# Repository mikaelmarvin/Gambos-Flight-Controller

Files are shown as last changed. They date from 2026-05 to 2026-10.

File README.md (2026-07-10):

# Gambos flight controller

Custom **STM32F446** flight-controller PCB and firmware — schematic through layout, manufacture, assembly, bring-up, application and driver development.

## At a glance

| | |
| ---| ---|
| **MCU** | STM32F446RET6 (Cortex-M4 + FPU) |
| **Sensors** | Accelerometer, gyroscope, magnetometer, barometer, temperature |
| **Storage** | External flash + microSD |
| **Actuation** | 5× hobby servo PWM, ESC motor PWM |
| **Wireless**  | nRF24L01+ telemetry / command link |
| **Debug** | SWD + UART (SEGGER J-Link) |
| **PCB** | 4-layer, 75 × 50 mm — KiCad, manufactured **v1.0** |
| **Firmware**  | CMake, FreeRTOS — `gambos-pcb` target |
| **Status** | v1.0 built; hardware bring-up in progress; flight software in progress |
| **Schematic** | [Gambos PCB schematic (PDF)](docs/gambos-pcb.pdf) — KiCad export, v1.0 |

## Schematic (v1.0)

The full board schematic is published as a PDF:

**[Gambos PCB schematic (PDF)](docs/gambos-pcb.pdf)**

The editable design lives in the KiCad project under [`hardware/`](hardware/); the PDF is an export of that source.

## Render and Bring-up setup

<p align="center">
  <table cellspacing="0" cellpadding="12">
    <tr>
      <td align="center" valign="top">
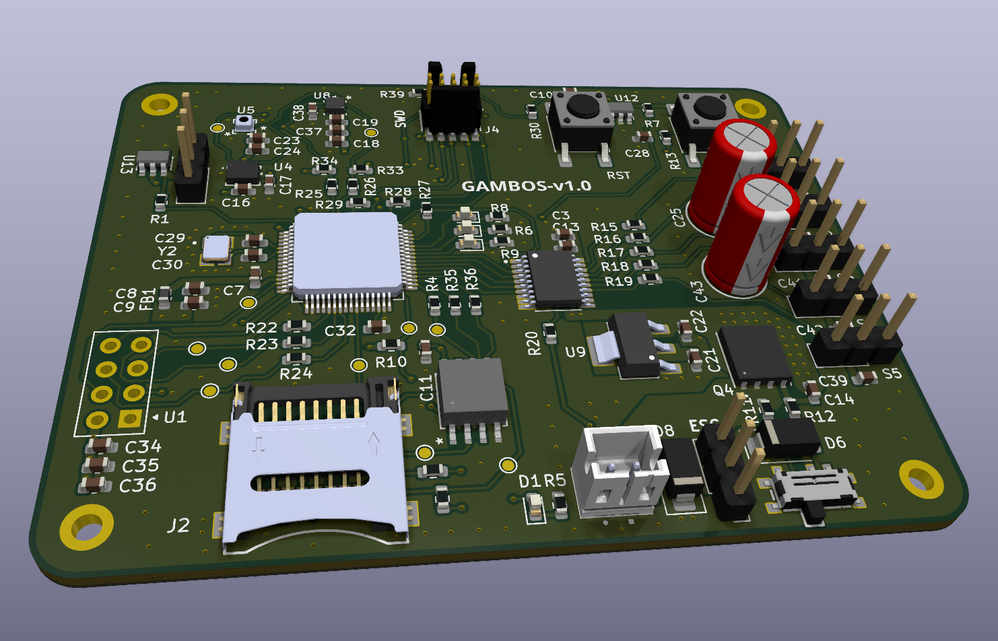
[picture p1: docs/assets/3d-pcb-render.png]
3D PCB render
        
        <br>
        <sub>3D PCB render</sub>
      </td>
      <td align="center" valign="top">
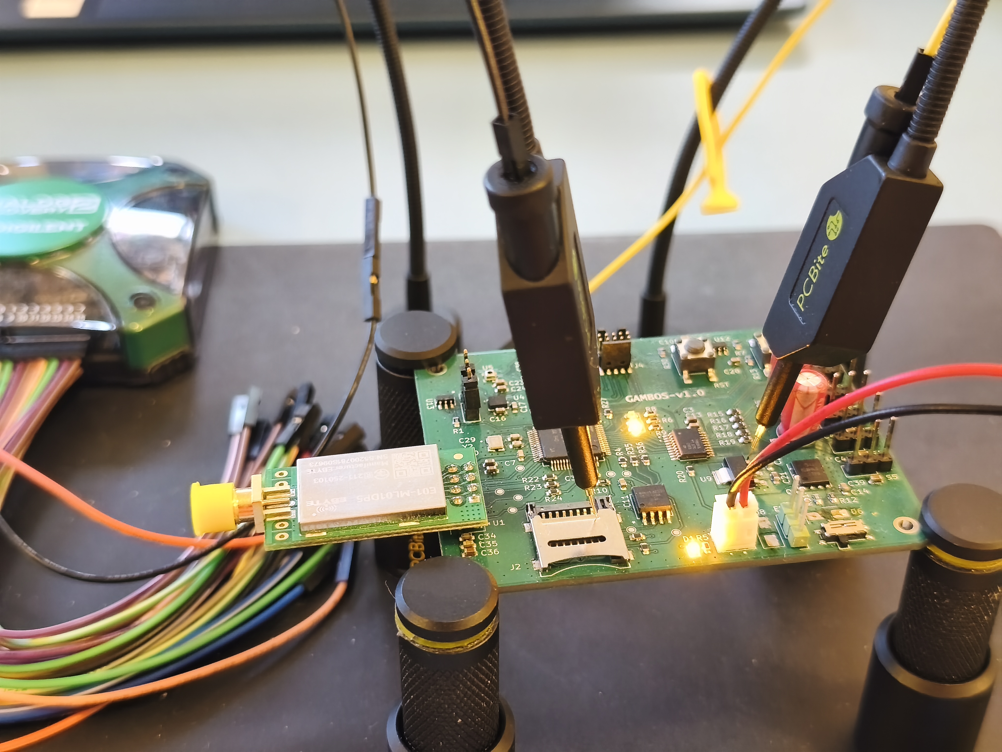
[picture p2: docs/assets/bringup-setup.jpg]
Bring-up setup on the bench
        
        <br>
        <sub>Testing the power section on the bench</sub>
      </td>
    </tr>
  </table>
</p>

Render of v1.0 layout in KiCad (left) and early bench bring-up (right), started with the power section before moving to testing other peripherals.

## Hardware block diagram

<p align="center">
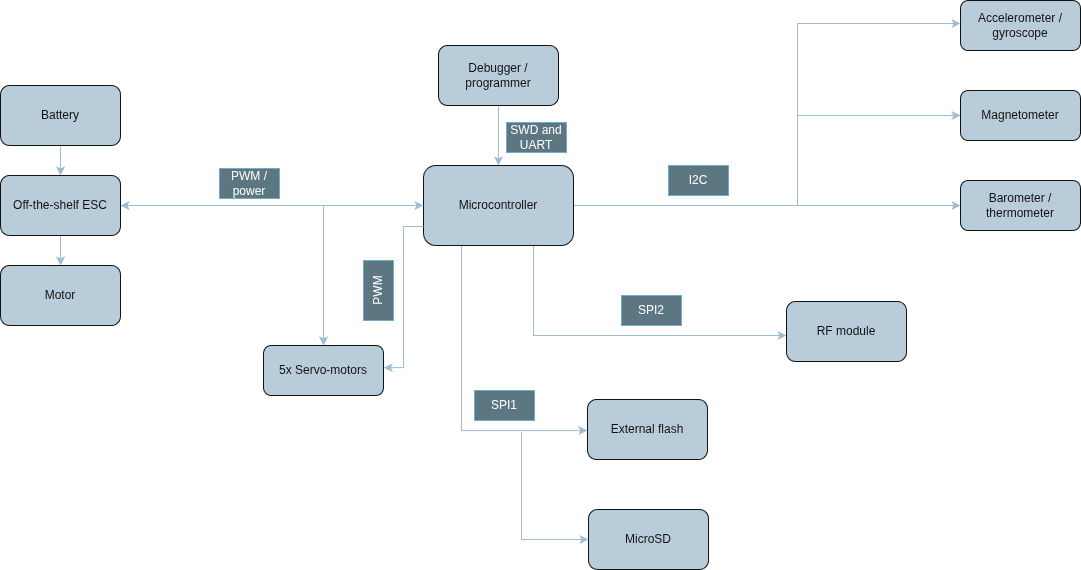
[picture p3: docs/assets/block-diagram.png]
System block diagram
  
  <br>
  <sub>Hardware block diagram</sub>
</p>

Buses, actuation, and interfaces are described in [Hardware architecture](docs/hardware/hardware-architecture.md).

## Software architecture

*(diagram pending)* — layer stack, drivers, RTOS tasks, and flight logic are described in [Software architecture](docs/software/software-architecture.md).

## Documentation

Full index: **[docs/index.md](docs/index.md)**

**Hardware** (read in order after this page):

1. [Hardware architecture](docs/hardware/hardware-architecture.md)
2. [Physical design](docs/hardware/physical-design.md)
3. [Power](docs/hardware/power.md) → [Storage](docs/hardware/storage.md) → [Sensing](docs/hardware/sensing.md) → [User interface](docs/hardware/user-interface.md)
4. [Roadmap](docs/hardware/roadmap.md) — v1.0 todos and v1.1+ hardware plans

**Software:** [docs/software/software-architecture.md](docs/software/software-architecture.md) → [software/README.md](software/README.md)

## Repository layout

| Directory | Purpose |
| --- | --- |
| `[hardware/](hardware/)` | KiCad project, libraries, manufacturing outputs |
| `[software/](software/)` | STM32 firmware (CMake, FreeRTOS) |
| `[docs/](docs/)` | Hardware and software documentation, figures |

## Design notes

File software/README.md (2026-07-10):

# Gambos firmware

STM32 firmware for the Gambos project — built with CMake, developed in a **Dev Container** (Docker) at the **repository root** (see the top-level `README.md`).

## Prerequisites

| Requirement | Notes |
| ---| ---|
| **Git** | Clone this repository. |
| **Docker** + **Docker Compose** | Used by the dev container. |
| **Cursor** or **VS Code** | With the **Dev Containers** extension (`ms-vscode-remote.remote-containers`). |
| **Host OS** | **Linux** recommended for **USB** (J-Link, serial) into the container. |

## First-time setup (after clone)

1. **Open the repo in the editor** and choose **“Reopen in Container”** (or **Dev Containers: Reopen in Container**).
2. Wait for the image to build and **post-create** to finish. The container runs `.devcontainer/setup.sh`, which runs `./software/project/scripts/build.sh`.
3. **Open a new terminal** so the shell prompt (Starship) and `PATH` are correct.

## Build, flash, probe, clean, and pristine

Run from the **repository root** via `software/project/scripts/`.

| Argument | Hardware | Debugger |
| --- | --- | --- |
| `gambos-pcb` (default) | Gambos PCB | **SEGGER J-Link** (`JLinkExe`) |

| Script | Role |
| ---| ---|
| `build.sh` | Configure + compile → `build/gambos-pcb/gambos.elf` |
| `clean.sh` | CMake `clean` |
| `pristine.sh` / `pristine.sh all` | Delete entire `build/` |
| `pristine.sh gambos-pcb` | Delete only `build/gambos-pcb/` |
| `flash.sh` | Program the MCU (build first) |
| `probe.sh` | Verify debugger connection |

```bash
./software/project/scripts/build.sh
./software/project/scripts/clean.sh
./software/project/scripts/pristine.sh          # or pristine.sh gambos-pcb | all
./software/project/scripts/flash.sh
./software/project/scripts/probe.sh             # optional before flash
```

## Editor / clangd (IntelliSense)

- `compile_commands.json` is generated under `software/project/build/gambos-pcb/` when you build. A symlink at `software/project/compile_commands.json` points at that directory.
- **clangd path mappings** in `.devcontainer/devcontainer.json` and `.vscode/settings.json` translate host paths (`/home/mikael/gambos`) and container paths (`/workspace/gambos`) so IntelliSense works whether you built on the host or in the Dev Container — no file rewriting.
- CMSIS-SVD for register view in Cortex-Debug: `software/STM32F446.svd` (referenced from `.vscode/launch.json`).
- `software/.clangd` points firmware sources at the `board` compilation database.
- If clangd is stale, run `./software/project/scripts/build.sh`, then **restart clangd** (command palette: **clangd: Restart language server**).

## Debugging

**Run and Debug (F5):** **Debug** or **Attach gambos-pcb (J-Link)** — see `.vscode/launch.json`. Symbols from `build/gambos-pcb/gambos.elf`; build (and flash if needed) first.

**Before F5**

1. In a terminal: `./software/project/scripts/build.sh` so the ELF exists and matches your code.
2. Optionally `flash.sh` / `probe.sh` if you want to verify outside the debugger.

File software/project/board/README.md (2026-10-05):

# Board support

## Gambos PCB (`gambos-pcb`)

`board/gambos-pcb/` is the **committed STM32CubeMX export** used by CMake.

| Path | Role |
|---|---|
| `board/gambos-pcb/` | CubeMX project (`.ioc`, `Core/`, HAL, FreeRTOS, generated CMake) |
| `app/gambos-pcb/` | Application code |
| `custom_drivers/` | Hardware drivers |

### CubeMX regeneration

1. Open `board/gambos-pcb/gambos-pcb.ioc` in CubeMX.
2. Generate code into the same `board/gambos-pcb/` directory (overwrite).
3. Review `git diff` — keep project hooks inside `USER CODE` blocks.
4. Build:

```bash
./software/project/scripts/build.sh
```

Put pins, clocks, timers, NVIC, and FreeRTOS parameters in the `.ioc`. Put application glue only in Cube `USER CODE` sections (for example `app_init()` in `Core/Src/main.c`).

`board/gambos-pcb/CMakeLists.txt` is **CubeIDE-only**. The firmware build uses `board/gambos-pcb/cmake/stm32cubemx/` via the top-level `CMakeLists.txt`.

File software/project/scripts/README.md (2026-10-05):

# `software/project/scripts`

Run these from the **repository root**.

## Probe & flash (Gambos PCB / J-Link)

| Command | Hardware | Probe | Flash |
|---|---|---|---|
| `./software/project/scripts/probe.sh` | Gambos PCB — **SEGGER J-Link** | `./software/project/scripts/probe.sh` | `./software/project/scripts/flash.sh` |

Build first:

```bash
./software/project/scripts/build.sh
```

Optional env:

- **`GAMBOS_FLASH_ELF`** — explicit ELF for `flash.sh`
- **`GAMBOS_JLINK_DEVICE`**, **`GAMBOS_JLINK_SPEED`** — J-Link tuning

## Other scripts

| Script | Role |
|---|---|
| `build.sh` | Configure + compile → `build/gambos-pcb/gambos.elf` |
| `clean.sh` | CMake `clean` for `gambos-pcb` |
| `pristine.sh` / `pristine.sh all` | Delete entire `build/` |
| `pristine.sh gambos-pcb` | Delete only `build/gambos-pcb/` |

USB debug probes need **`/dev/bus/usb`** (see repo `docker-compose.yml`). Install SEGGER in the image (repo `Dockerfile`) and rebuild the Dev Container.

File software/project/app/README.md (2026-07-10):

# Application

The Gambos PCB application lives in `app/gambos-pcb/`. Sources are listed in `app/gambos-pcb/CMakeLists.txt` (included from the top-level `CMakeLists.txt`).

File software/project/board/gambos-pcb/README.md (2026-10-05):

# Gambos PCB — CubeMX board tree

Committed STM32CubeMX export for the Gambos PCB. CMake builds this directory directly.

- Edit hardware config in `gambos-pcb.ioc`, then regenerate into this folder.
- Keep project-specific C hooks inside `USER CODE` blocks only.
- Application code lives in `app/gambos-pcb/`; drivers in `custom_drivers/`.

See [`../README.md`](../README.md) for the regeneration workflow.

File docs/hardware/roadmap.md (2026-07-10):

# Roadmap

Open work on **v1.0** (current board, firmware, and docs in this repository) and planned changes for **later hardware iterations**. Move items to done as they complete; add v1.1+ entries only when they target a new PCB spin, not v1.0 bring-up.

## Current iteration (v1.0)

### Hardware

- Document assembly and bench test procedure (or link from bring-up notes)

### Firmware

- Complete Gambos PCB peripheral bring-up on `gambos-pcb` preset (I2C sensors, SPI flash, SD, SPI2 RF)
- RTOS task layout, drivers, and messaging (see [Software architecture](../software/software-architecture.md))
- Sensor fusion and control loops for fixed-wing flight
- In-flight logging on external flash; post-flight copy to SD
- Telemetry protocol over nRF24L01+

### Documentation

- Software architecture page: layer diagram, tasks, drivers structure
- Hardware pages: fill placeholders (e.g. power measurements, LDO notes)
- BOM with manufacturer part numbers in repo or linked spreadsheet
- Testing of bulk capacitors on servo motors and their response -> osciloscope measuring

## Next hardware iteration (v1.1+)

Changes intended for a **future PCB revision** after v1.0 bring-up and flight tests — not general repo todos.

### Fixes from v1.0 bring-up

- S2 pin, which is dedicated to the SERVO2 motor cannot be mapped to a hardware generated PWM signal in stm32cubemx, thus making this hardware version not be able to control 5 servos, but 4 (S1, S3, S4, S5).

### Design improvements under consideration

- Copper pour and stitching can be done in a more elegant way
- Add a GNSS module with a ready made antenna, 
- BLE would be interesting
- Humidity sensor
- Ditch the MUTAG ESD component; it is a nightmare to solder -> general component selection optimized for easier soldering

---

**Next:** [Documentation index →](../index.md)

[Repository README](../../README.md) · [Documentation index](../index.md)

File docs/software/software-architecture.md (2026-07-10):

# Software architecture

Firmware for Gambos lives under [`software/`](../../software/).

| | |
| --- | --- |
| **MCU** | STM32F446 — Gambos PCB (`gambos-pcb`) |
| **Build** | CMake, FreeRTOS, STM32 HAL |
| **Status** | Build/flash workflow documented; flight-stack architecture docs not written yet |

## Getting started

**[software/README.md](../../software/README.md)** — Dev Container, build, flash, and debug scripts.

## Software architecture *(documentation in progress)*

Expand these sections on this page (or add linked pages) as the stack matures. The [repository README](../../README.md) lists the same placeholders for recruiters landing on the repo root.

## Related documentation

- [Repository README](../../README.md)
- [Hardware architecture](../hardware/hardware-architecture.md)
- [Roadmap](../hardware/roadmap.md)

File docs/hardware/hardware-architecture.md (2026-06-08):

# Hardware architecture

**Schematic:** [Gambos PCB schematic (PDF)](../gambos-pcb.pdf) (KiCad v1.0 export).

## Block diagram

System block diagram

## Digital communication

### Sensors (I2C)

All primary flight sensors (accelerometer, gyroscope, magnetometer, barometer) share one **I2C** bus. This keeps routing and pin usage simple; bandwidth is sufficient at the planned sample rates.

### Non-volatile storage (SPI1)

**External flash** and the **microSD** card share **SPI1**. Flash holds high-rate in-flight logs; the SD card is used after flight to copy data for long-term storage, so firmware can avoid bus contention during flight.

### Telemetry (SPI2)

The **nRF24L01+** uses **SPI2** on its own bus so the RF driver does not share the SPI peripheral with storage devices — simpler firmware and predictable timing.

## Actuation and power control

### Flight surfaces

Five servos are driven by **hardware PWM**. They are powered from the ESC **BEC** rail so high-current inductive loads stay off the logic supply.

### Propulsion

The brushless motor is driven by a dedicated **PWM** signal to the ESC. Battery power routes directly from the Li-Po pack to the ESC high-voltage inputs.

## Debugging and development

### SWD (Serial Wire Debug)

A dedicated header supports flashing, breakpoints, and real-time variable inspection.

### Serial console (UART)

UART on the debug header streams development logs and telemetry during bring-up.

---

**Next:** [Physical design →](physical-design.md)

[Documentation index](../index.md)

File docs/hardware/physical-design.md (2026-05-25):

# Physical design

The board uses a **4-layer stackup** for signal integrity and power distribution:

| Layer | Role |
| ---| ---|
| 1 (Top) | Signal / power |
| 2 | Ground plane |
| 3 | Ground plane |
| 4 (Bottom) | Signal / power |

Dual internal ground planes give a low-impedance return path. Outer layers use copper pours for thermal spread and to limit warping during reflow and hand soldering.

**Board size:** 75 × 50 mm

<p align="center">
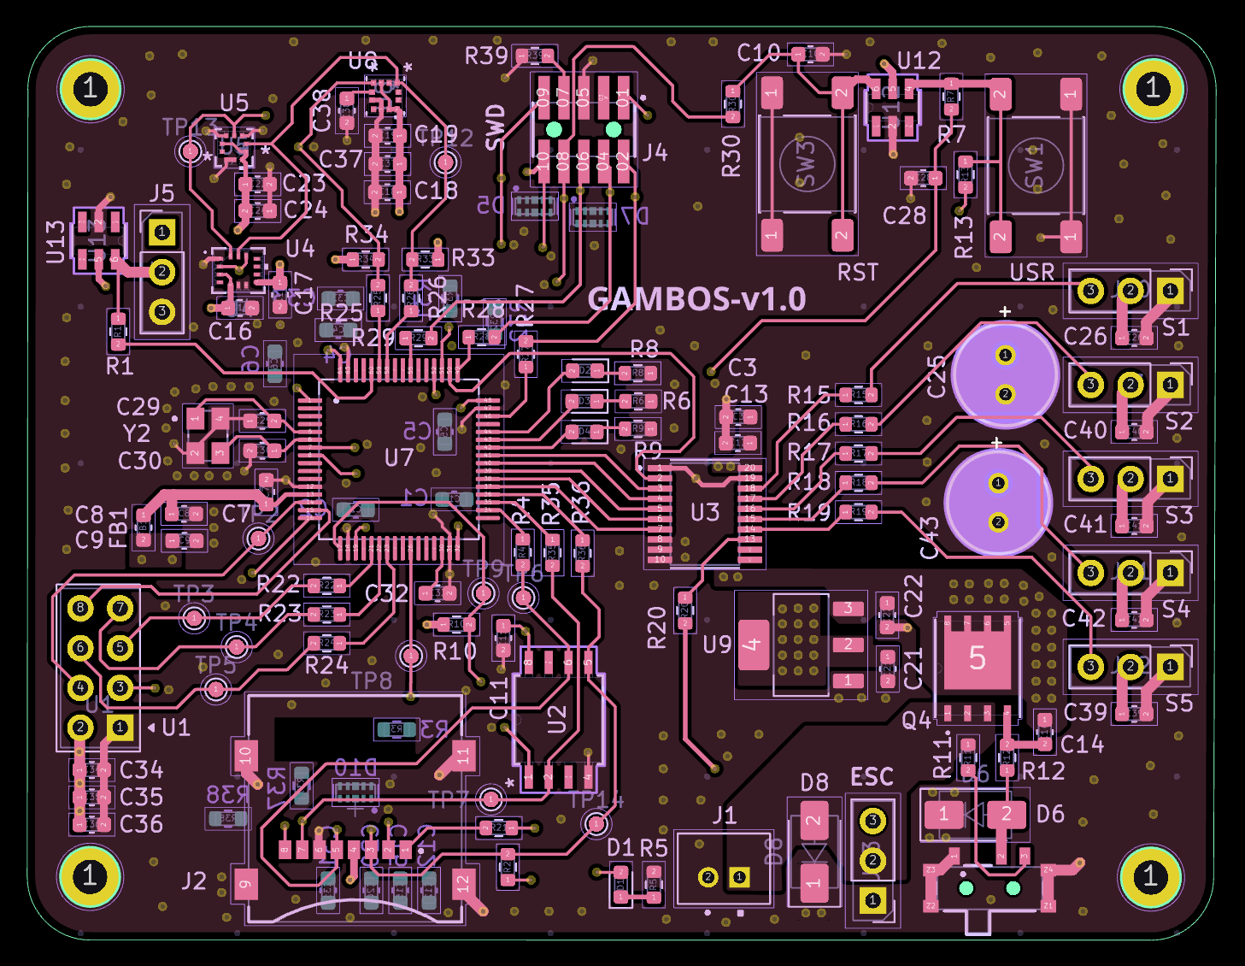
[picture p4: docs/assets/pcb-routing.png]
PCB routing
  
  <br>
  <sub>Top-layer with copper pour</sub>
</p>

---

**Next:** [Power →](power.md)

[Documentation index](../index.md)

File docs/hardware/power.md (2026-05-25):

# Power section

The power path feeds the **servo rail (5 V BEC)** and the **logic rail (3.3 V)** from the battery input. A slide switch and **high-side PMOS** enable the high-current 5 V path; an **LDO** derives 3.3 V for the MCU and sensors.

| Block | Role |
| ----- | ---- |
| Slide switch | Main input enable |
| High-side PMOS + soft-start (C14) | Switched 5 V to servos; limits inrush |
| LDO | 5 V → 3.3 V for MCU and sensors |
| Bulk / decoupling | Rail stability on 5 V and 3.3 V |
| Servo headers | High-current outputs on the BEC path |

## Schematic

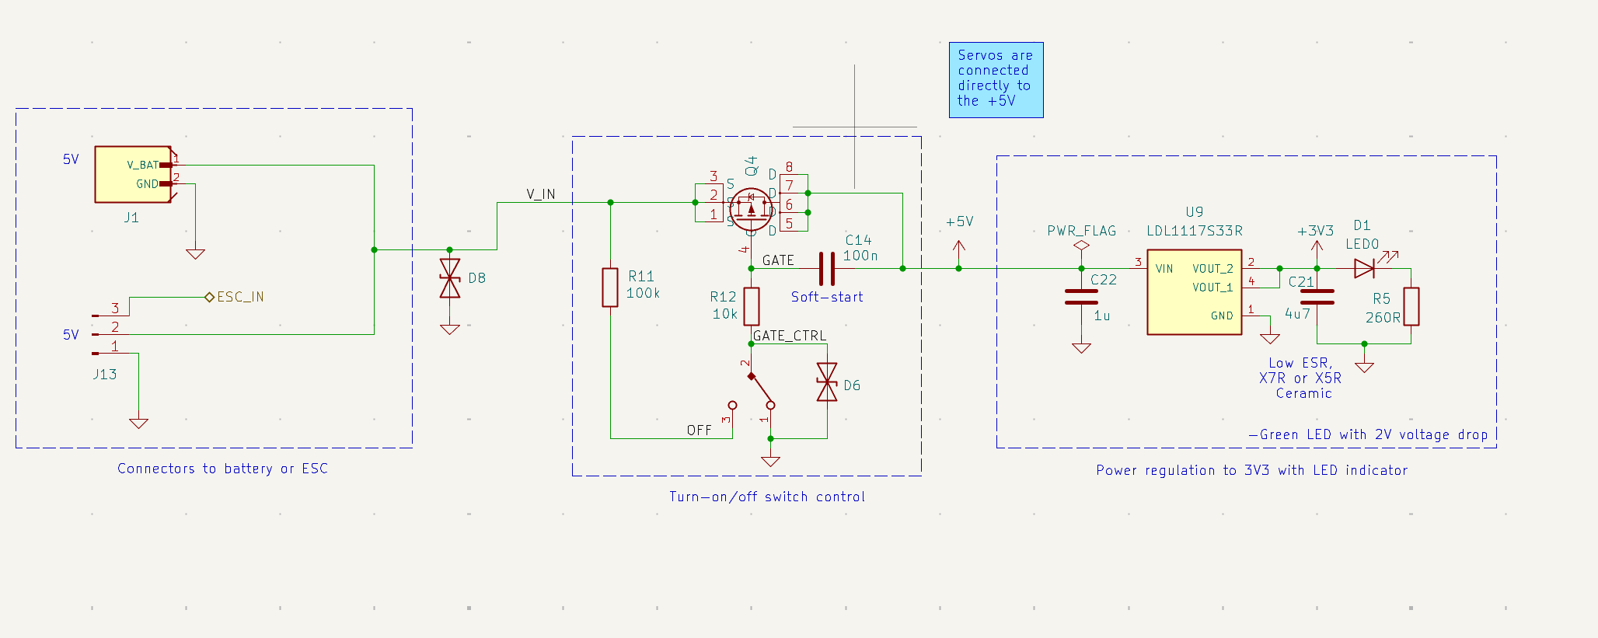
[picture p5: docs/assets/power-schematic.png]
Power schematic


## Design — high-side PMOS and soft-start

A **high-side PMOS** switches the board on and off. Five hobby servos on the **5 V** rail draw large **stall currents**, and bulk capacitance on that rail produces a high **inrush** if the FET turns on instantly.

A **100 nF soft-start capacitor (C14)** between gate and drain slows the turn-on and limits inrush. The FET is sized for roughly **750 mA** per servo stall; design headroom targets **~5 A** steady capability with inrush limited to about **10 A for 1 ms**, in line with the device datasheet. At the intended gate drive, **R<sub>DS(on)</sub>** is on the order of **10 mΩ**, so conduction loss stays acceptable even during short high-current events.

## Design — LDO (3.3 V)

*(Brief note on LDO choice, input range, and expected load — MCU + sensors on 3.3 V.)*

---

## Simulation (LTspice)

Pre-layout checks in LTspice; schematics and `.asc` files can live under `hardware/` or a linked archive when added.

| Plot | File (add under `docs/assets/`) | What it should show |
| ---- | --- | --- |
| Soft-start / inrush | `power-soft-start-sim.png` | Gate drive and 5 V rail during enable |
| PMOS switch / load | `power-pmos-load-sim.png` | Steady-state or switched load on 5 V |
| LDO transient *(optional)* | `power-ldo-load-sim.png` | 3.3 V during load step on logic rail |

### Soft-start and inrush

<!-- Replace with your LTspice plot when ready:
<p align="center">
  <img src="../assets/power-soft-start-sim.png" alt="LTspice soft-start simulation">
  <br>
  <sub>LTspice — soft-start / inrush (conditions: …)</sub>
</p>
-->

*Plot pending.*

**Takeaways**

- *(e.g. Peak inrush below 10 A for 1 ms with C14 = 100 nF.)*
- *(e.g. 5 V rail reaches regulation within … ms.)*

### PMOS switch under load

*Plot pending.*

**Takeaways**

- *(Steady R<sub>DS(on)</sub> loss vs. expected servo stall current.)*

### LDO load step *(optional)*

*Plot pending.*

**Takeaways**

- *(3.3 V droop and recovery with MCU + sensor load model.)*

---

## Bench measurements (oscilloscope)

Measurements on the **v1.0** board during bring-up. Record **probe point**, **scope settings**, and **load** (bench supply vs. battery, servos connected or not) in each caption so plots stay comparable later.

| Measurement | File (add under `docs/assets/`) | Typical probe / condition |
| --- | --- | --- |
| Enable / inrush | `power-inrush-scope.png` | 5 V rail or FET drain; slide switch on |
| 5 V rail steady | `power-5v-scope.png` | BEC rail under load |
| 3.3 V rail | `power-3v3-scope.png` | LDO output; logic load |

### Enable and inrush

<!-- Example figure block (match physical-design.md / README caption style):
<p align="center">
  <img src="../assets/power-inrush-scope.png" alt="Oscilloscope capture — inrush">
  <br>
  <sub>Scope — 5 V enable (CH1: …, CH2: …, load: …)</sub>
</p>
-->

*Capture pending.*

**Observations**

- *(Does measured inrush match simulation within …?)*
- *(Any overshoot or ringing worth noting?)*

### 5 V rail (servo / BEC)

*Capture pending.*

### 3.3 V rail (LDO)

*Capture pending.*

---

## Simulation vs. measurement

Short comparison after both sets of plots are in place:

| Check | Simulation | Measured | Pass? |
| ----- | --- | --- | ----- |
| Peak inrush | | | |
| 5 V regulation | | | |
| 3.3 V regulation | | | |

---

## Summary

- **Switching:** PMOS + C14 soft-start limits inrush while supporting multi-servo stall current.
- **Simulation:** *(one line — what LTspice confirmed.)*
- **Bench:** *(one line — what scope measurements confirmed on v1.0.)*

---

**Next:** [Storage →](storage.md)

[Documentation index](../index.md)

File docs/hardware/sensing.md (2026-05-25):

# Sensing section

The sensing section includes:

- **Accelerometer and gyroscope** (combined IMU)
- **Magnetometer**
- **Barometer** (with temperature)

## Schematic

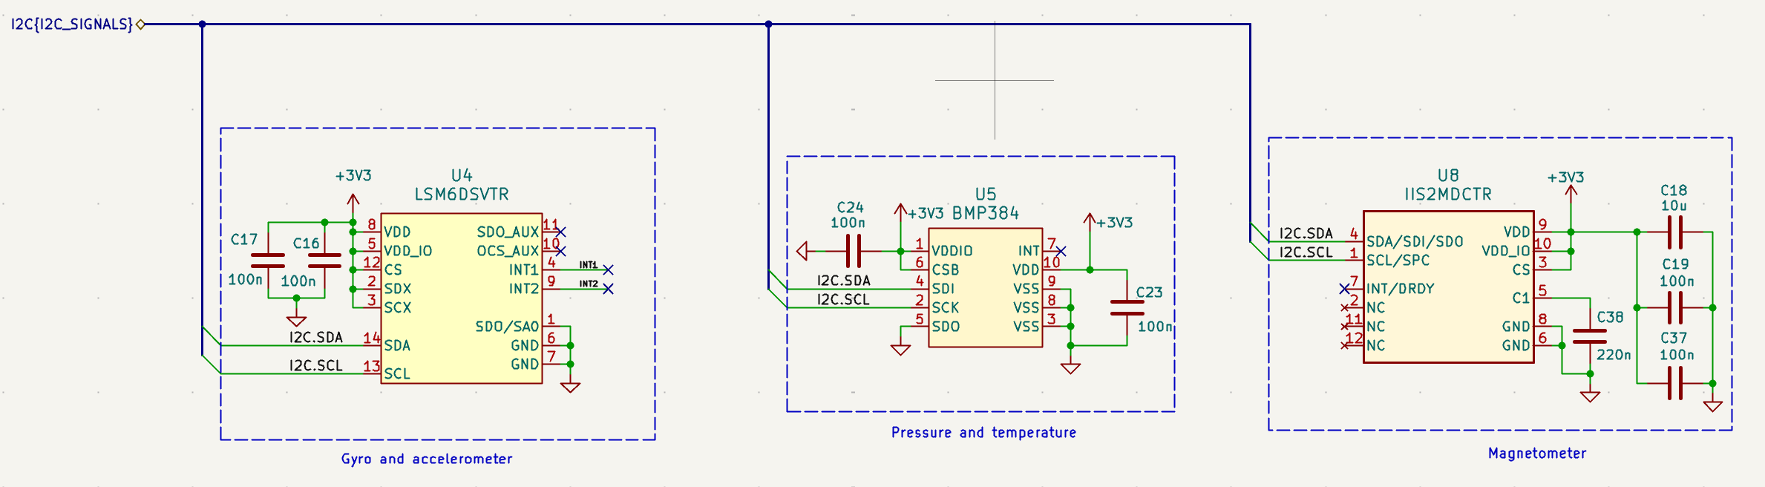
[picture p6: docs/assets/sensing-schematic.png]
Sensing schematic


## Communication interface and strategy

All sensors share one **I2C** bus to reduce pin count and routing complexity.

Sensors run at different sample rates, so firmware must serialize access (dedicated I2C task, mutexes or semaphores, etc.) — see the firmware tree under `software/project/`.

## Routing and layout

- Pull-ups **R33** and **R34** are **4.7 kΩ**, with alternate footprints to tune rise time if needed.
- Series **0 Ω** parts (**R25**, **R26**) support later testing.

## PCB layout

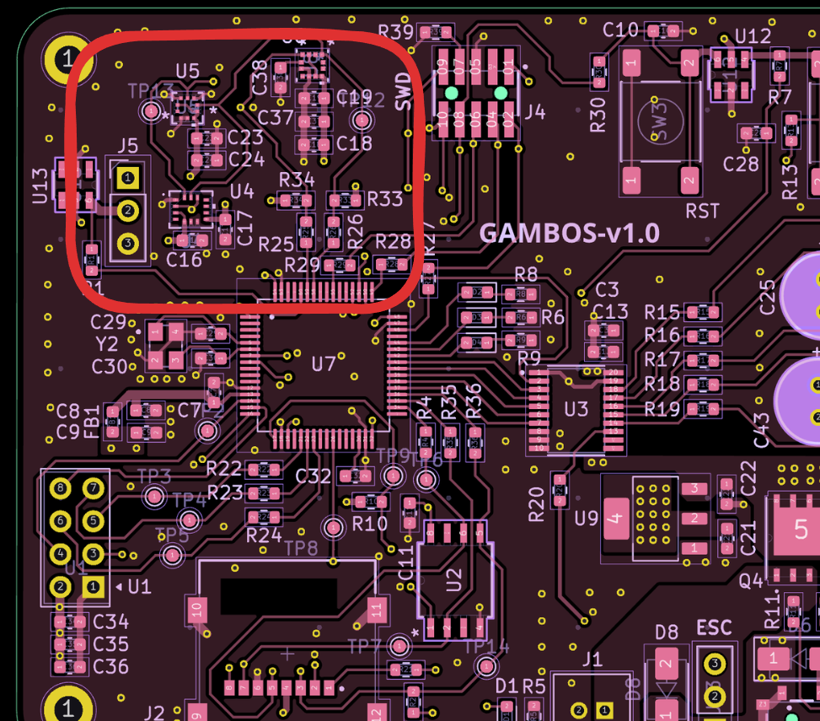
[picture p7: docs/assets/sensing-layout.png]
Sensing PCB layout


---

**Next:** [User interface →](user-interface.md)

[Documentation index](../index.md)

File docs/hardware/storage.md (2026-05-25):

# Storage section

The storage section includes:

- **External flash** — fast non-volatile logging
- **MicroSD socket** — removable storage and post-flight data export

## Schematic

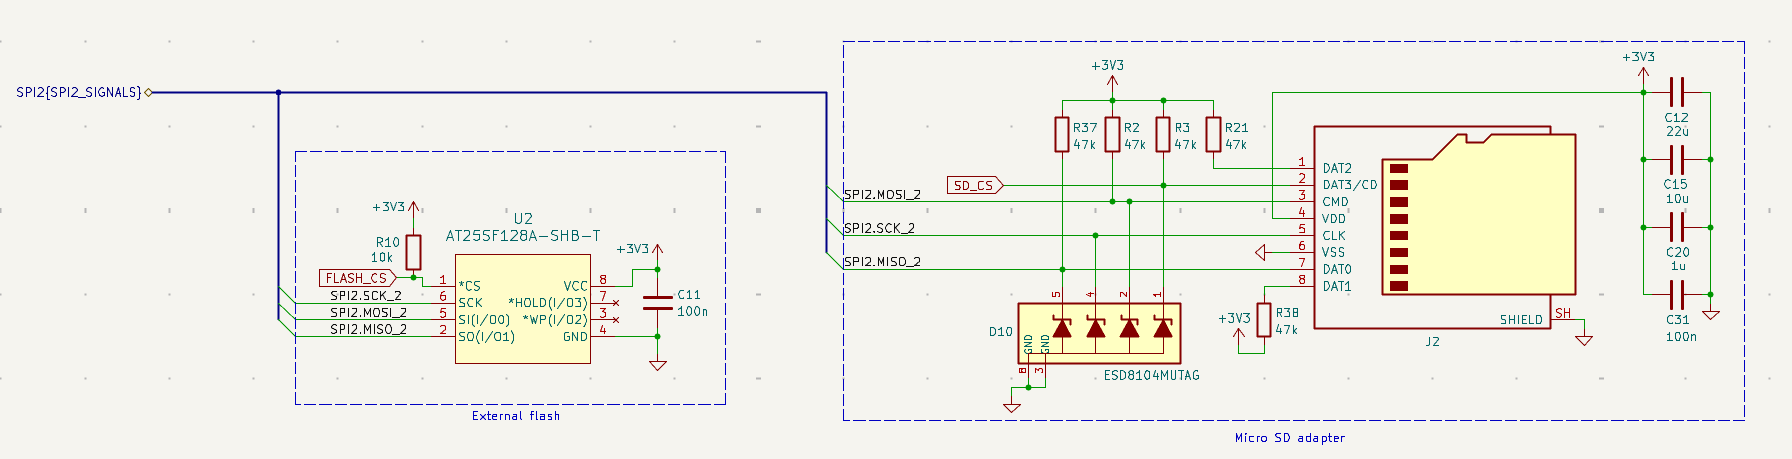
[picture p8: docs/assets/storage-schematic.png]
Storage schematic


## Communication interface and strategy

Both devices share **SPI1**.

| Phase | Active device | Rationale |
|---|---|---|
| In flight | External flash only | High-speed logging without SD card contention |
| Post flight | MicroSD | Copy logs from flash for long-term storage and analysis |

This sequencing keeps firmware bus arbitration simple during flight.

## Routing and layout

- SPI traces stay on one layer where practical; **0 Ω** series parts allow signal-integrity experiments.
- Pull-ups meet the SD card specification for stable logic levels.
- **ESD protection (D10)** on user-accessible data lines reduces risk when inserting or removing cards.

## PCB layout

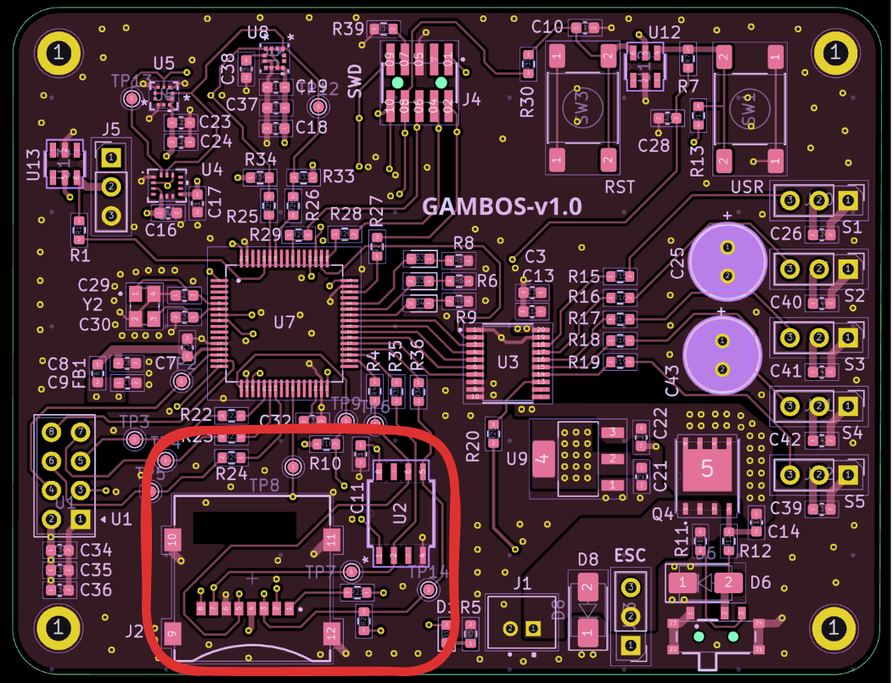
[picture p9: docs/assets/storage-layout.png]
Storage PCB layout


---

**Next:** [Sensing →](sensing.md)

[Documentation index](../index.md)

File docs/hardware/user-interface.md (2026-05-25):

# User interface section

The user section includes:

- **nRF24L01+** RF module
- **User push button**
- **Three status LEDs** (yellow)

## Schematic

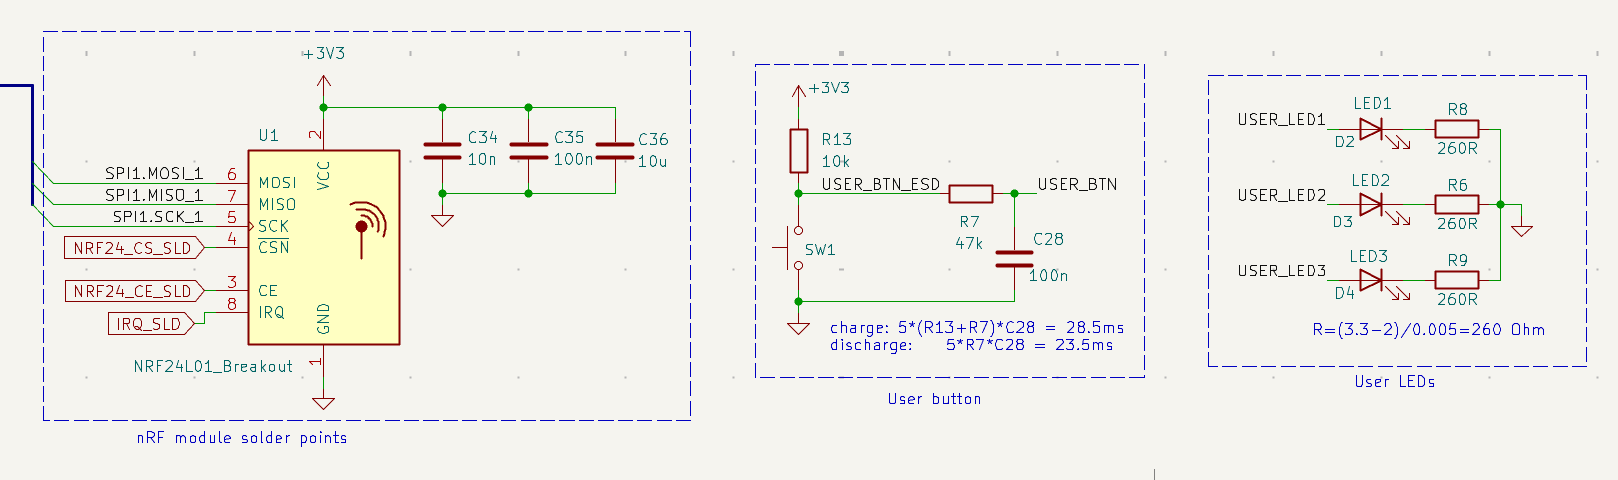
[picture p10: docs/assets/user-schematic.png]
User interface schematic


## nRF24L01+ transceiver

Handles wireless telemetry and command reception. It connects to **SPI2**; no other peripheral shares that bus, so the driver avoids SPI arbitration with storage devices.

## Push button

Hardware **RC debouncing** filters contact bounce. Used for tests, debug workflows, and triggering or stopping specific routines during bring-up.

## Status LEDs

Three LEDs give visual feedback during power-on, tests, and runtime debug.

---

**Next:** [Roadmap →](roadmap.md)

[Documentation index](../index.md)

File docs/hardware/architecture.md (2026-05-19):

# System architecture

## Block diagram

<p align="center">
  System block diagram
</p>

## Digital communication

### Sensors (I2C)

All primary flight sensors (accelerometer, gyroscope, magnetometer, barometer) share one **I2C** bus. This keeps routing and pin usage simple; bandwidth is sufficient at the planned sample rates.

### Non-volatile storage (SPI1)

**External flash** and the **microSD** card share **SPI1**. Flash holds high-rate in-flight logs; the SD card is used after flight to copy data for long-term storage, so firmware can avoid bus contention during flight.

### Telemetry (SPI2)

The **nRF24L01+** uses **SPI2** on its own bus so the RF driver does not share the SPI peripheral with storage devices — simpler firmware and predictable timing.

## Actuation and power control

### Flight surfaces

Five servos are driven by **hardware PWM**. They are powered from the ESC **BEC** rail so high-current inductive loads stay off the logic supply.

### Propulsion

The brushless motor is driven by a dedicated **PWM** signal to the ESC. Battery power routes directly from the Li-Po pack to the ESC high-voltage inputs.

## Debugging and development

### SWD (Serial Wire Debug)

A dedicated header supports flashing, breakpoints, and real-time variable inspection.

### Serial console (UART)

UART on the debug header streams development logs and telemetry during bring-up.

## Related documentation

- [Physical design](physical-design.md)
- [Power](power.md) · [Storage](storage.md) · [Sensing](sensing.md) · [User interface](user-interface.md)

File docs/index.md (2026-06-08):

# Gambos documentation

Technical documentation for the Gambos flight controller: custom hardware (KiCad) and STM32 firmware (CMake + FreeRTOS).

**Start here:** [repository README](../README.md) — project overview, block diagram, bring-up, and links into hardware and software docs.

**Schematic (v1.0):** [Gambos PCB schematic (PDF)](gambos-pcb.pdf) — full KiCad export for review.

## Hardware

Subsystem pages (read in order; each links to the next):

1. [Hardware architecture](hardware/hardware-architecture.md) — buses, actuation, debug interfaces
2. [Physical design](hardware/physical-design.md) — stackup, dimensions, PCB layout
3. [Power](hardware/power.md) — input switching, LDO, servo rail
4. [Storage](hardware/storage.md) — external flash and microSD
5. [Sensing](hardware/sensing.md) — IMU, magnetometer, barometer
6. [User interface](hardware/user-interface.md) — RF module, button, LEDs
7. [Roadmap](hardware/roadmap.md) — v1.0 open work and planned next hardware iterations

## Software

- [Software architecture](software/software-architecture.md) — firmware layers and placeholders for stack docs
- [Build, flash, debug](../software/README.md)

## Repository entry points

- [Repository README](../README.md)
- [KiCad project](../hardware/gambos-pcb.kicad_pro)
- [Firmware](../software/)

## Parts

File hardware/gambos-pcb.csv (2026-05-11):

Reference | Qty | Value
Y2 | 1 | TSX-3225_26MHZ
U12,U13 | 2 | CM1293A-04SO
U9 | 1 | LDL1117S33R
U8 | 1 | IIS2MDCTR
U7 | 1 | STM32F446RET6
U5 | 1 | BMP384
U4 | 1 | LSM6DSVTR
U3 | 1 | SN74AHCT541PWR
U2 | 1 | AT25SF128A-SHB-T
U1 | 1 | NRF24L01_Breakout
TP2,TP3,TP4,TP5,TP6,TP7,TP8,TP9,TP12,TP13,TP14 | 11 | TestPoint
SW1,SW3 | 2 | SW_Push
Slide_SW1 | 1 | 450404015514
R39 | 1 | 100R
R33,R34 | 2 | 4k7
R30 | 1 | 470R
R11 | 1 | 100k
R5,R6,R8,R9 | 4 | 260R
R4,R15,R16,R17,R18,R19,R20,R22,R23,R24,R25,R26,R27,R28,R29,R31,R32,R35,R36 | 19 | 0R
R2,R3,R7,R21,R37,R38 | 6 | 47k
R1,R10,R12,R13 | 4 | 10k
Q4 | 1 | DMP3010LPSQ-13
J5,J7,J9,J10,J11,J12,J13 | 7 | Conn_01x03_Pin
J4 | 1 | FTSH-105-01-F-DV-K-A
J2 | 1 | Micro_SD_Card
J1 | 1 | JST-PH
FB1 | 1 | 120R
D6,D8 | 2 | SMAJ5.0CA
D5,D7,D10 | 3 | ESD8104MUTAG
D4 | 1 | LED3
D3 | 1 | LED2
D2 | 1 | LED1
D1 | 1 | LED0
C38 | 1 | 220n
C29,C30 | 2 | 8p
C25,C43 | 2 | 470u
C21,C32 | 2 | 4u7
C12 | 1 | 22u
C7,C34 | 2 | 10n
C6,C15,C18,C26,C36,C39,C40,C41,C42 | 9 | 10u
C3,C8,C9,C20,C22 | 5 | 1u
C1,C2,C4,C5,C10,C11,C13,C14,C16,C17,C19,C23,C24,C28,C31,C33,C35,C37 | 18 | 100n

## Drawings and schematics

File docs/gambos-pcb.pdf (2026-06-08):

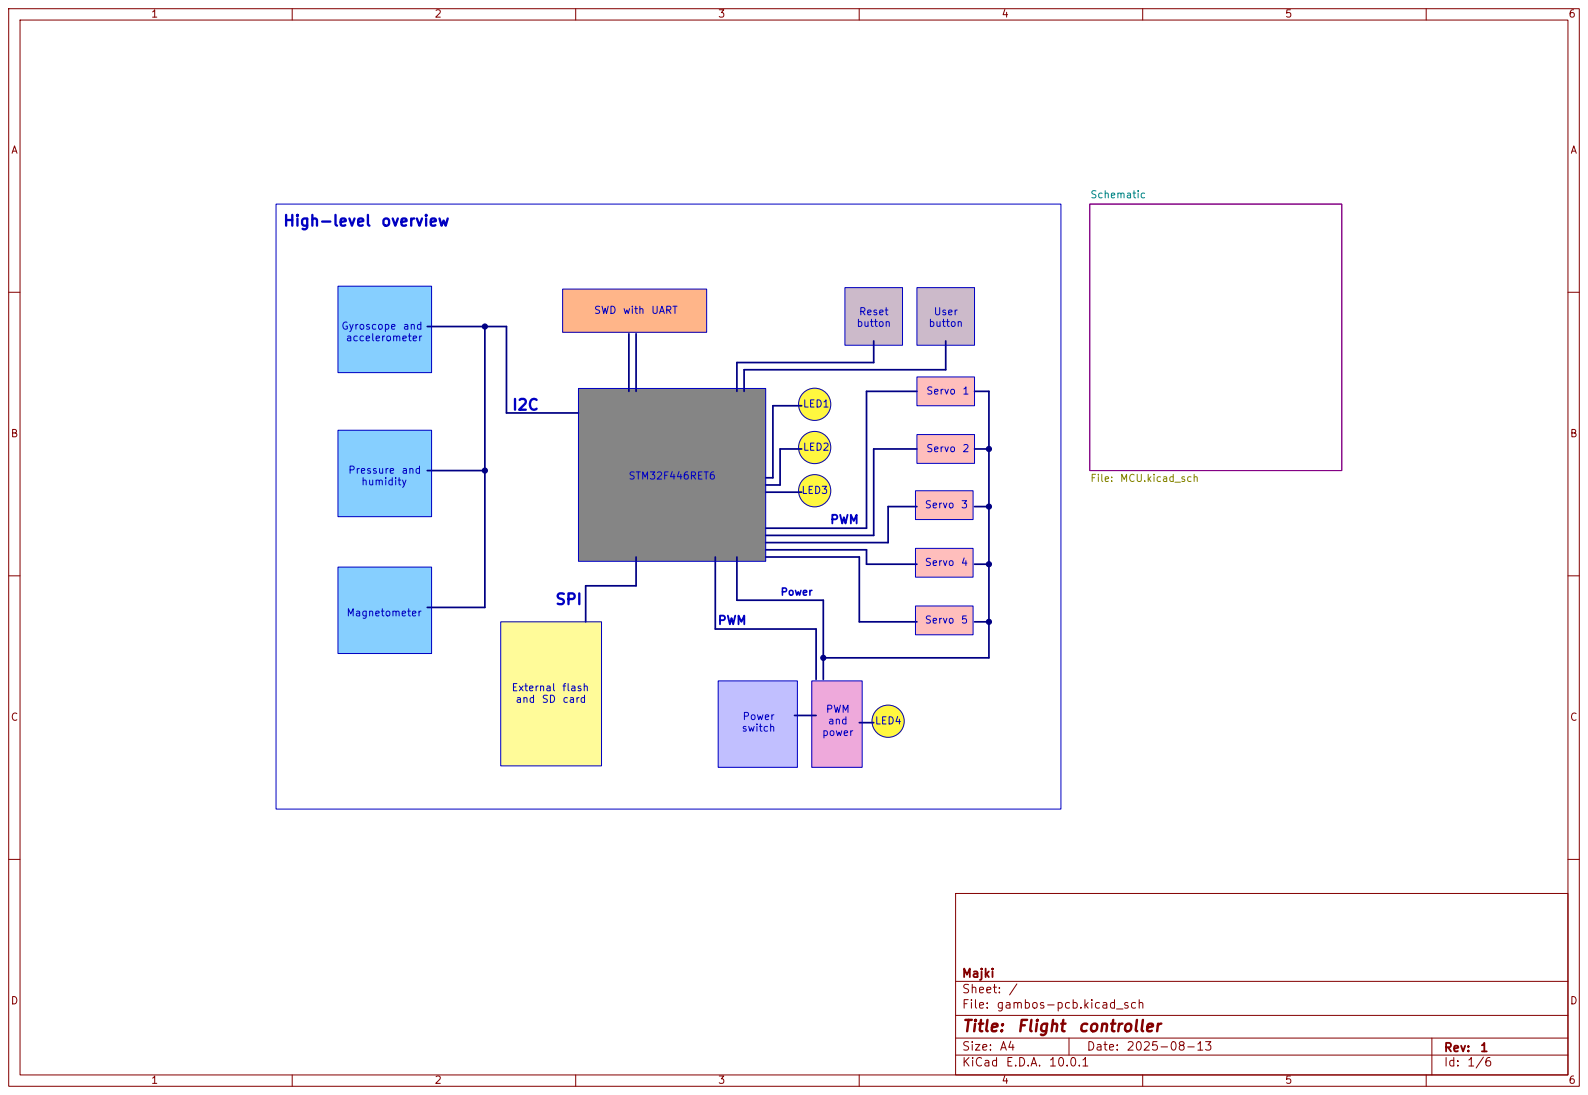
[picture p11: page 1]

Size: A4 | Rev: 1
KiCad E.D.A. 10.0.1 | Id: 1/6

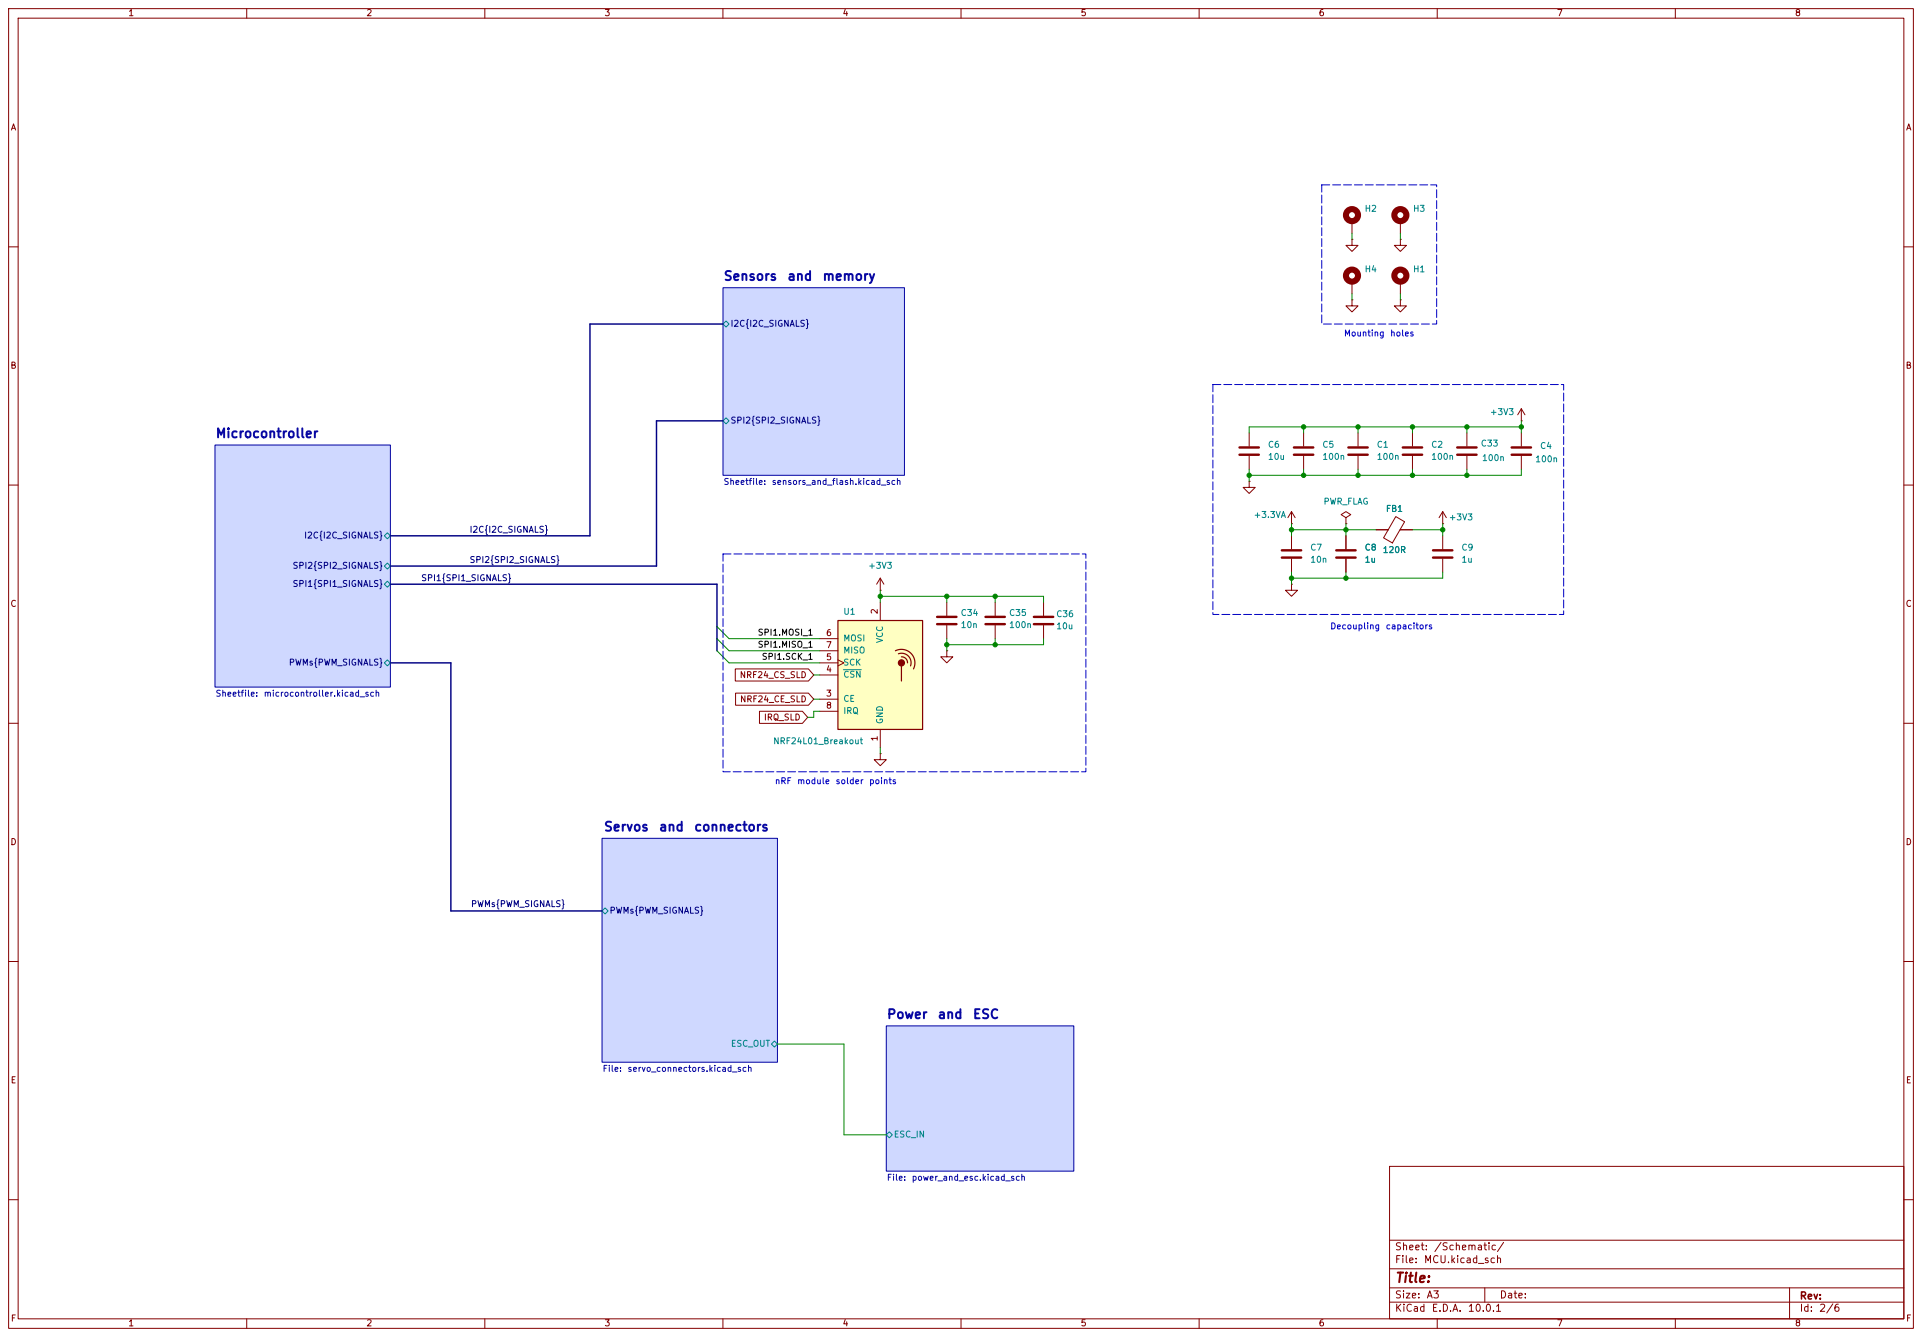
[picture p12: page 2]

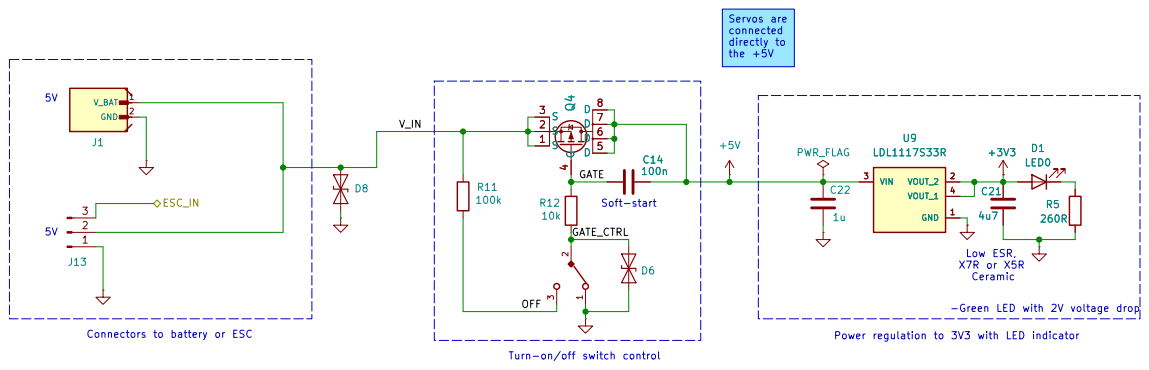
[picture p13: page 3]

the +5V Connectors to battery or ESC

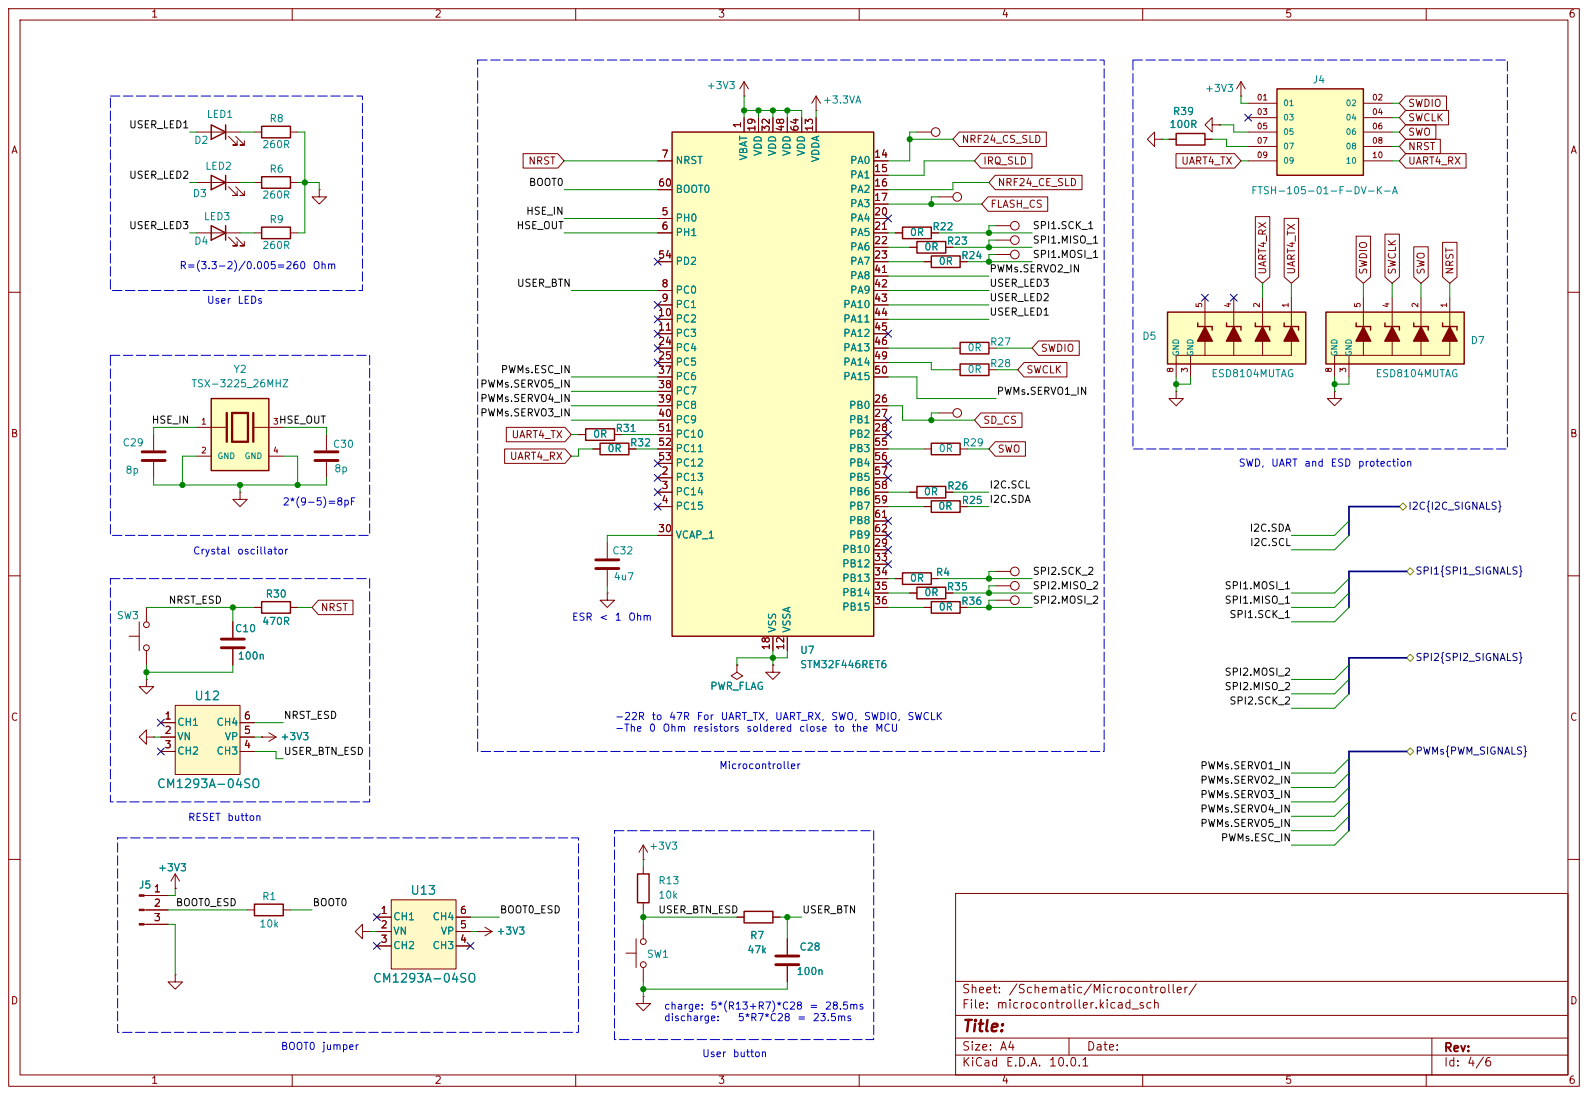
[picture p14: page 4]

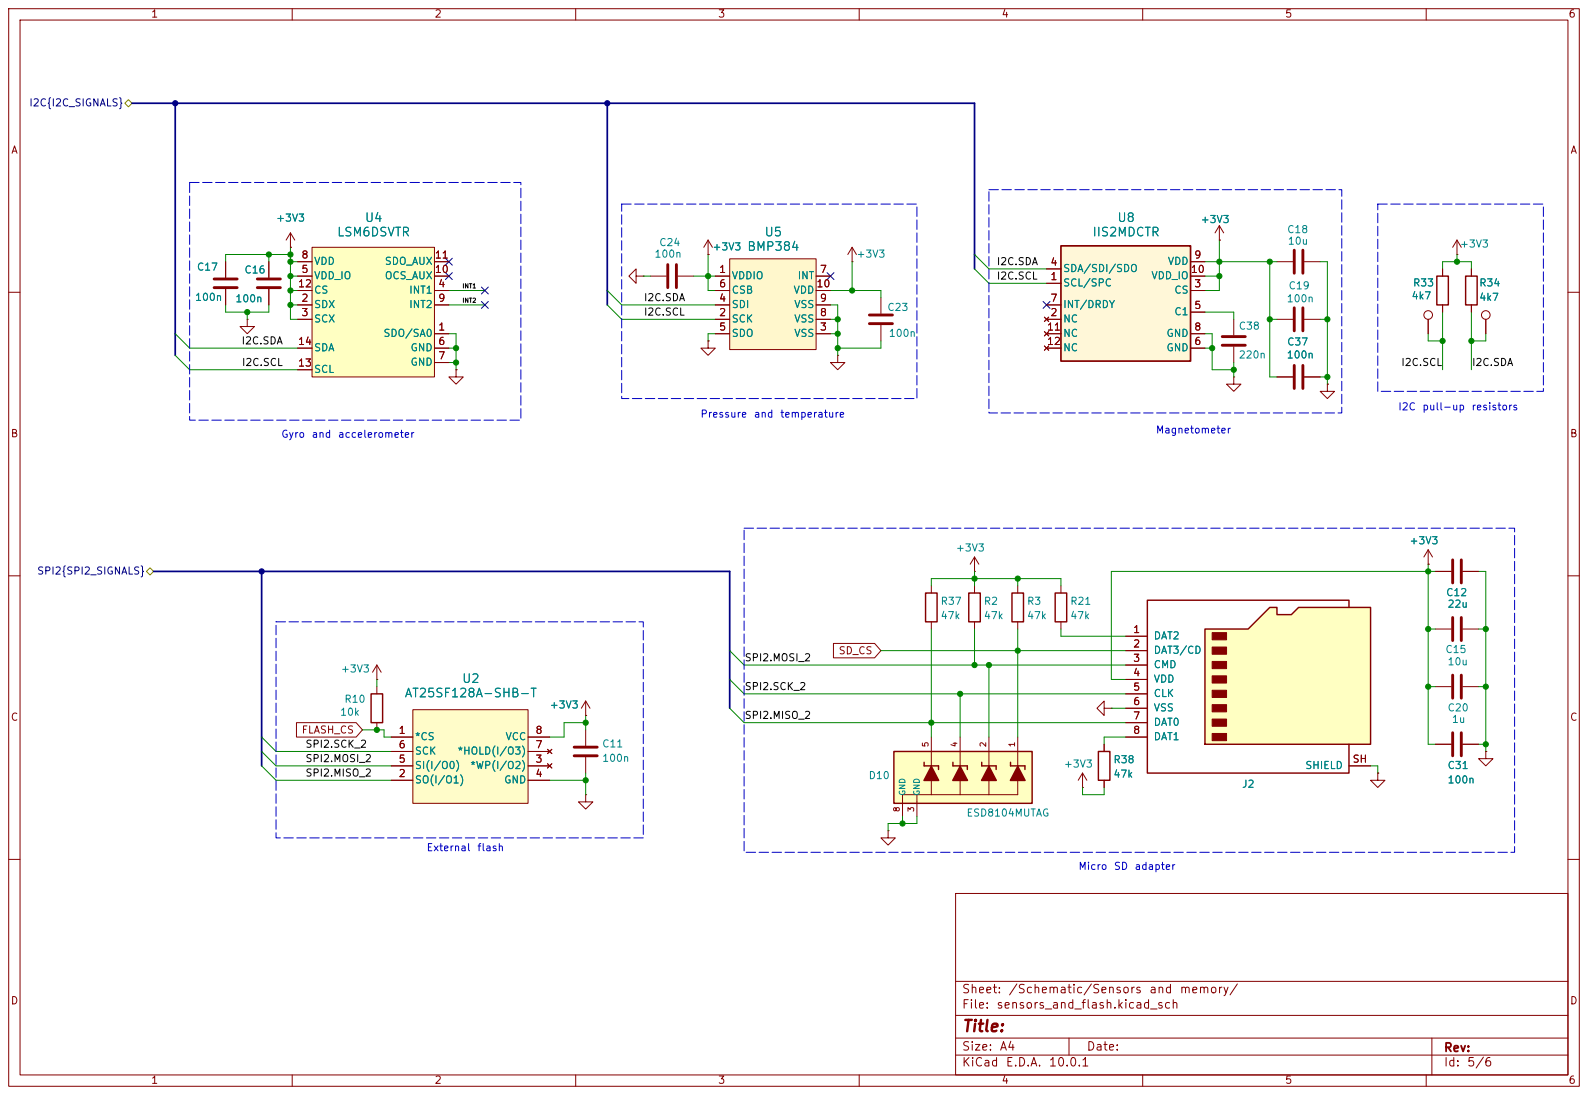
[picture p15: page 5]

I2C pull-up resistors Magnetometer

Sheet: /Schematic/Sensors and memory/
File: sensors_and_flash.kicad_sch
Title:

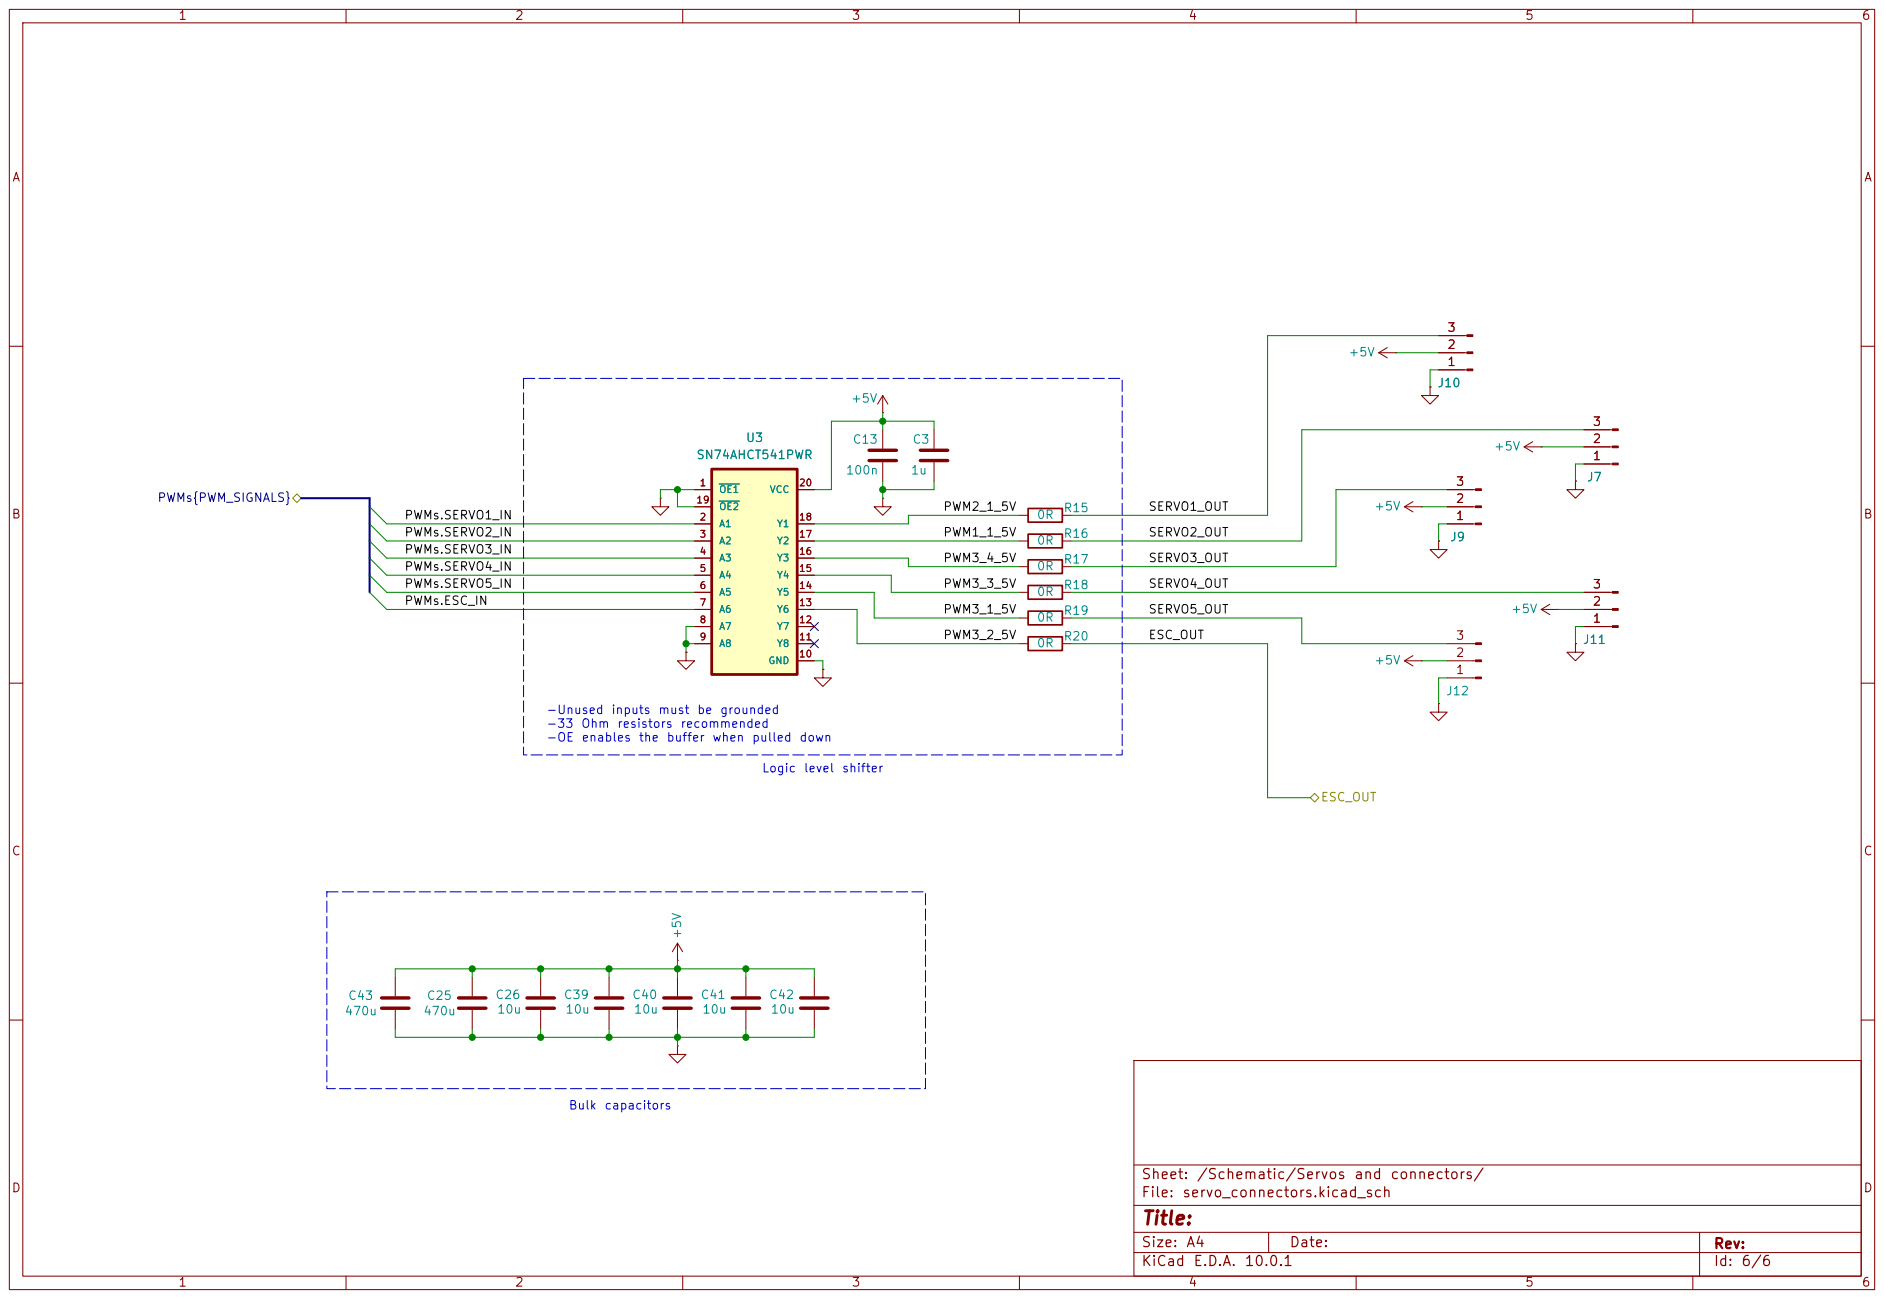
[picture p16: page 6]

Logic level shifter Bulk capacitors

Sheet: /Schematic/Servos and connectors/
File: servo_connectors.kicad_sch
Title:

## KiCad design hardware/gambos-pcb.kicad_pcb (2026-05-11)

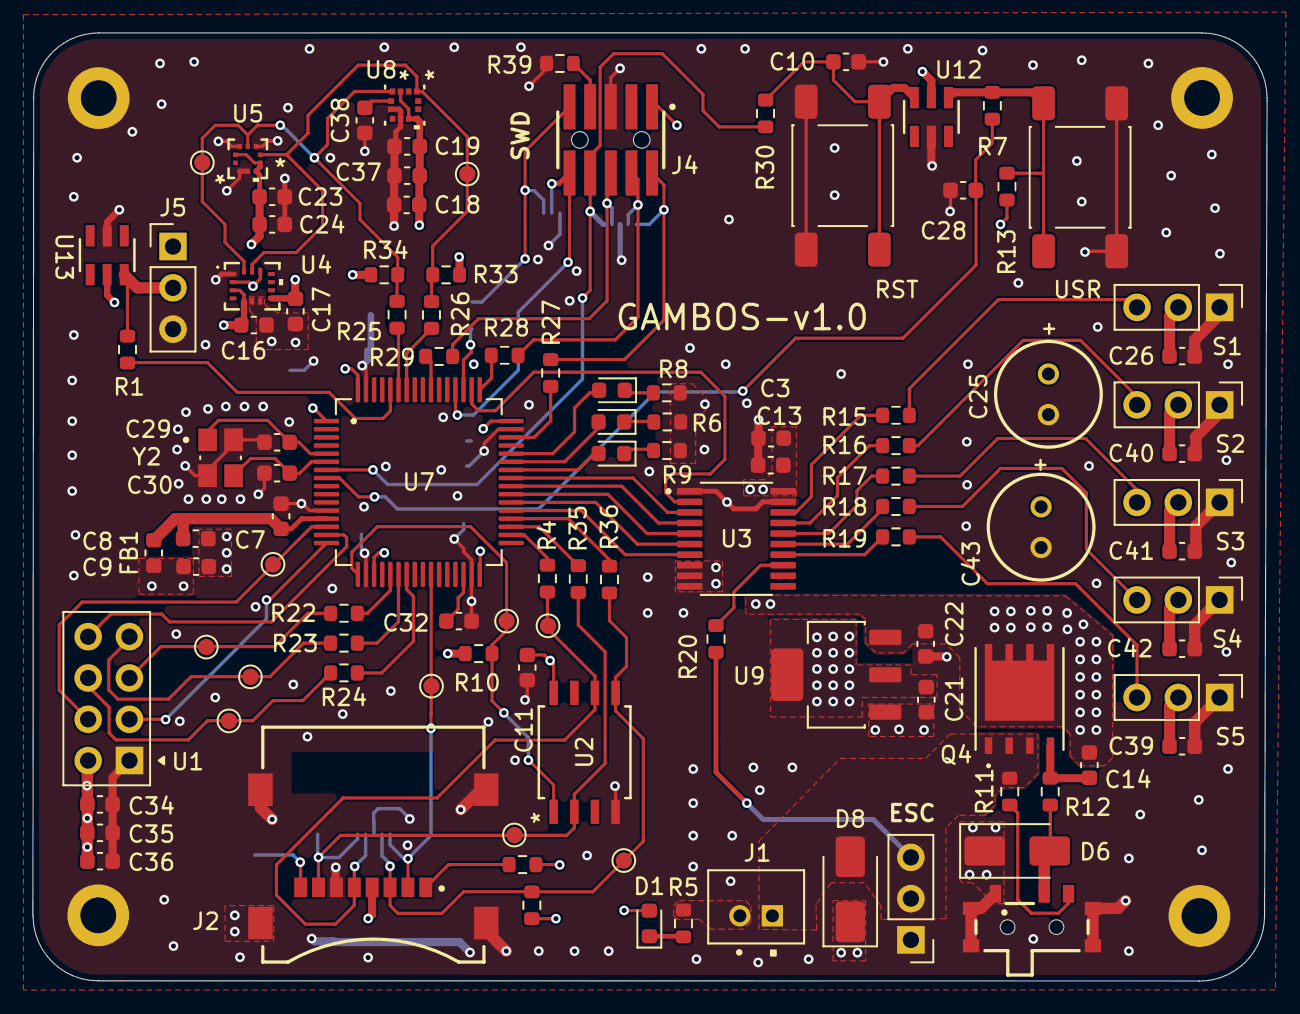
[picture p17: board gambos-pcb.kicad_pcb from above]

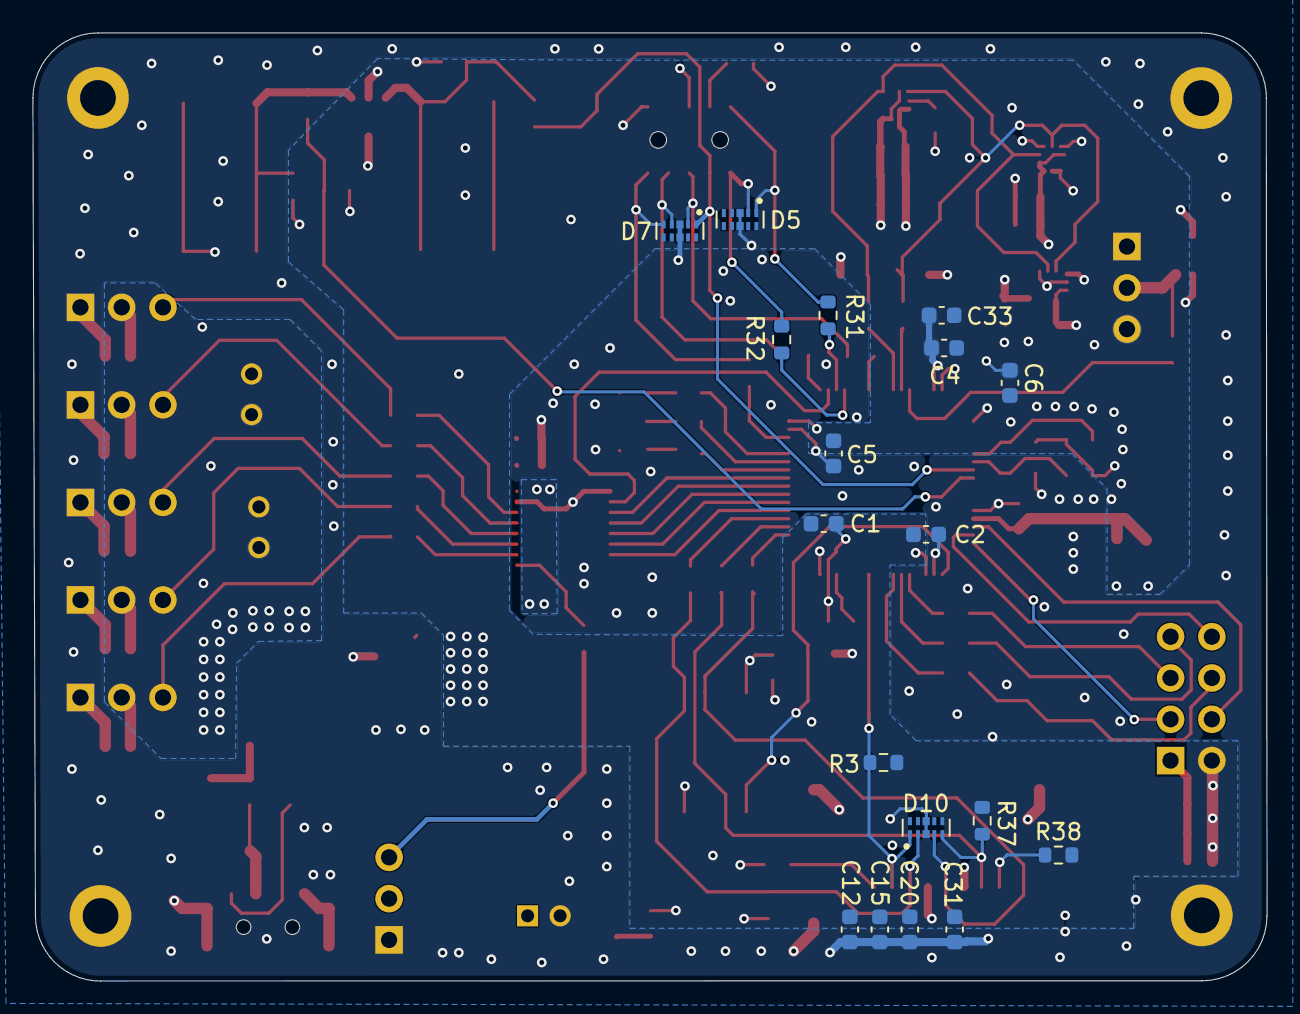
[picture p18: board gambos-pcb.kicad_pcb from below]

Board: 4 copper layers, 75.9 x 58.3 mm, 130 parts (18 on the bottom side), 77 nets.

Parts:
C1, C2, C4, C5, C10, C11, C13, C14, C16, C17, C19, C23, C24, C28, C31, C33, C35, C37: 100n; C_0603_1608Metric
C3, C8, C9, C20, C22: 1u; C_0603_1608Metric
C6, C15, C18, C26, C36, C39, C40, C41, C42: 10u; C_0603_1608Metric
C7, C34: 10n; C_0603_1608Metric
C12: 22u; C_0603_1608Metric
C21, C32: 4u7; C_0603_1608Metric
C25, C43: 470u; WCAP-ATG8_6.3X11_DXL_
C29, C30: 8p; C_0603_1608Metric
C38: 220n; C_0603_1608Metric
D1: LED0; LED_0603_1608Metric
D2: LED1; LED_0603_1608Metric
D3: LED2; LED_0603_1608Metric
D4: LED3; LED_0603_1608Metric
D5, D7, D10: ESD8104MUTAG; DIO_ESD8104MUTAG
D6, D8: SMAJ5.0CA; D_SMA
FB1: 120R; L_0603_1608Metric
H1, H2, H3, H4: MountingHole_Pad; MountingHole_2.2mm_M2_DIN965_Pad
J1: JST-PH
J2: Micro_SD_Card; GCT_MEM2067-02-180-00-A_REVB
J4: FTSH-105-01-F-DV-K-A; SAMTEC_FTSH-105-01-F-DV-K-A
J5, J7, J9, J10, J11, J12, J13: Conn_01x03_Pin; PinHeader_1x03_P2.54mm_Vertical
Q4: DMP3010LPSQ-13
R1, R10, R12, R13: 10k; R_0603_1608Metric
R2, R3, R7, R21, R37, R38: 47k; R_0603_1608Metric
R4, R15, R16, R17, R18, R19, R20, R22, R23, R24, R25, R26, R27, R28, R29, R31, R32, R35, R36: 0R; R_0603_1608Metric
R5, R6, R8, R9: 260R; R_0603_1608Metric
R11: 100k; R_0603_1608Metric
R30: 470R; R_0603_1608Metric
R33, R34: 4k7; R_0603_1608Metric
R39: 100R; R_0603_1608Metric
SW1, SW3: SW_Push; SW_Push_1P1T_NO_E-Switch_TL3301NxxxxxG
Slide_SW1: 450404015514
TP2, TP3, TP4, TP5, TP6, TP7, TP8, TP9, TP12, TP13, TP14: TestPoint; TestPoint_Pad_D1.0mm
U1: NRF24L01_Breakout; nRF24L01_Breakout
U2: AT25SF128A-SHB-T; IC8_AT25SF128A-SHB-T_ADO
U3: SN74AHCT541PWR; SOP65P640X120-20N
U4: LSM6DSVTR
U5: BMP384; LGA10_2.0X2.0X0.95_BOS
U7: STM32F446RET6
U8: IIS2MDCTR; LGA-12_2X2X0P7_STM
U9: LDL1117S33R
U12, U13: CM1293A-04SO; SC74-6_3P1X1P7_ONS
Y2: TSX-3225_26MHZ; XTAL_TSX-3225_26.0000MF09Z-AC0

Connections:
+3.3VA: C7.1, C8.1, FB1.1, U7.13 (VDDA)
+3V3: C1.1, C2.1, C4.1, C5.1, C6.1, C9.1, C11.1, C12.2, C15.2, C16.1, C17.1, C18.1, C19.1, C20.2, C21.1, C23.1, C24.2, C31.2, C33.1, C34.1, C35.1, C36.1, C37.1, D1.2 (A), FB1.2, J2.4 (VDD), J4.01, J5.1, R2.1, R3.1, R10.1, R13.2, R21.1, R33.1, R34.1, R37.1, R38.2, U1.2 (VCC), U2.8 (VCC), U4.2 (SDX), U4.3 (SCX), U4.5 (VDD_IO), U4.8 (VDD), U4.12 (CS), U5.1 (VDDIO), U5.6 (CSB), U5.10 (VDD), U7.1 (VBAT), U7.19 (VDD), U7.32 (VDD), U7.48 (VDD), U7.64 (VDD), U8.3 (CS), U8.9 (VDD), U8.10 (VDD_IO), U9.2 (VOUT_2), U9.4 (VOUT_1), U12.5 (VP), U13.5 (VP)
+5V: C3.1, C13.1, C14.1, C22.1, C25.1, C26.1, C39.1, C40.1, C41.1, C42.1, C43.1, J7.2, J9.2, J10.2, J11.2, J12.2, Q4.5 (D), Q4.6 (D), Q4.7 (D), Q4.8 (D), U3.20 (VCC), U9.3 (VIN)
/Schematic/I2C.SCL: R26.2, R33.2, TP12.1 (1_1), U4.13 (SCL), U5.2 (SCK), U8.1 (SCL/SPC)
/Schematic/I2C.SDA: R25.2, R34.2, TP13.1 (1_1), U4.14 (SDA), U5.4 (SDI), U8.4 (SDA/SDI/SDO)
/Schematic/Microcontroller/BOOT0: R1.2, U7.60 (BOOT0)
/Schematic/Microcontroller/BOOT0_ESD: J5.2, R1.1, U13.6 (CH4)
/Schematic/Microcontroller/HSE_IN: C29.2, U7.5 (PH0), Y2.1
/Schematic/Microcontroller/HSE_OUT: C30.1, U7.6 (PH1), Y2.3
/Schematic/Microcontroller/NRST_ESD: C10.1, R30.1, SW3.2, U12.6 (CH4)
/Schematic/Microcontroller/PWMs.ESC_IN: U3.7 (A6), U7.37 (PC6)
/Schematic/Microcontroller/PWMs.SERVO1_IN: U3.2 (A1), U7.50 (PA15)
/Schematic/Microcontroller/PWMs.SERVO2_IN: U3.3 (A2), U7.41 (PA8)
/Schematic/Microcontroller/PWMs.SERVO3_IN: U3.4 (A3), U7.40 (PC9)
/Schematic/Microcontroller/PWMs.SERVO4_IN: U3.5 (A4), U7.39 (PC8)
/Schematic/Microcontroller/PWMs.SERVO5_IN: U3.6 (A5), U7.38 (PC7)
/Schematic/Microcontroller/USER_BTN: C28.1, R7.2, U7.8 (PC0)
/Schematic/Microcontroller/USER_BTN_ESD: R7.1, R13.1, SW1.2, U12.4 (CH3)
/Schematic/Microcontroller/USER_LED1: D2.2 (A), U7.44 (PA11)
/Schematic/Microcontroller/USER_LED2: D3.2 (A), U7.43 (PA10)
/Schematic/Microcontroller/USER_LED3: D4.2 (A), U7.42 (PA9)
/Schematic/Power and ESC/GATE: C14.2, Q4.4 (G), R12.2
/Schematic/Power and ESC/GATE_CTRL: D6.2 (A2), R12.1, Slide_SW1.2
/Schematic/Power and ESC/OFF: R11.2, Slide_SW1.3
/Schematic/Power and ESC/V_IN: D8.2 (A2), J1.1 (V_BAT), J13.2, Q4.1 (S), Q4.2 (S), Q4.3 (S), R11.1
/Schematic/SPI1.MISO_1: R23.2, TP4.1 (1_1), U1.7 (MISO)
/Schematic/SPI1.MOSI_1: R24.2, TP5.1 (1_1), U1.6 (MOSI)
/Schematic/SPI1.SCK_1: R22.2, TP3.1 (1_1), U1.5 (SCK)
/Schematic/SPI2.MISO_2: D10.5, J2.7 (DAT0), R35.2, R37.2, TP7.1 (1_1), U2.2 (SO(I/O1))
/Schematic/SPI2.MOSI_2: D10.2, J2.3 (CMD), R2.2, R36.2, TP14.1 (1_1), U2.5 (SI(I/O0))
/Schematic/SPI2.SCK_2: D10.4, J2.5 (CLK), R4.2, TP6.1 (1_1), U2.6 (SCK)
/Schematic/Servos and connectors/ESC_OUT: J13.3, R20.2
/Schematic/Servos and connectors/PWM1_1_5V: R16.1, U3.17 (Y2)
/Schematic/Servos and connectors/PWM2_1_5V: R15.1, U3.18 (Y1)
/Schematic/Servos and connectors/PWM3_1_5V: R19.1, U3.14 (Y5)
/Schematic/Servos and connectors/PWM3_2_5V: R20.1, U3.13 (Y6)
/Schematic/Servos and connectors/PWM3_3_5V: R18.1, U3.15 (Y4)
/Schematic/Servos and connectors/PWM3_4_5V: R17.1, U3.16 (Y3)
/Schematic/Servos and connectors/SERVO1_OUT: J10.3, R15.2
/Schematic/Servos and connectors/SERVO2_OUT: J7.3, R16.2
/Schematic/Servos and connectors/SERVO3_OUT: J9.3, R17.2
/Schematic/Servos and connectors/SERVO4_OUT: J11.3, R18.2
/Schematic/Servos and connectors/SERVO5_OUT: J12.3, R19.2
FLASH_CS: R10.2, TP9.1 (1_1), U2.1 (*CS), U7.17 (PA3)
GND: C1.2, C2.2, C3.2, C4.2, C5.2, C6.2, C7.2, C8.2, C9.2, C10.2, C11.2, C12.1, C13.2, C15.1, C16.2, C17.2, C18.2, C19.2, C20.1, C21.2, C22.2, C23.2, C24.1, C25.2, C26.2, C28.2, C29.1, C30.2, C31.1, C32.2, C33.2, C34.2, C35.2, C36.2, C37.2, C38.2, C39.2, C40.2, C41.2, C42.2, C43.2, D5.3 (GND), D5.8 (GND), D6.1 (A1), D7.3 (GND), D7.8 (GND), D8.1 (A1), D10.3 (GND), D10.8 (GND), H1.1 (1_1), H2.1 (1_1), H3.1 (1_1), H4.1 (1_1), J1.2 (GND), J2.6 (VSS), J2.9, J2.10, J2.11, J2.12, J4.05, J5.3, J7.1, J9.1, J10.1, J11.1, J12.1, J13.1, R5.2, R6.1, R8.1, R9.1, R39.1, SW1.1, SW3.1, Slide_SW1.1, Slide_SW1.Z1, Slide_SW1.Z2, Slide_SW1.Z3, Slide_SW1.Z4, U1.1 (GND), U2.4 (GND), U3.1 (~OE1), U3.8 (A7), U3.9 (A8), U3.10 (GND), U3.19 (~OE2), U4.1 (SDO/SA0), U4.6 (GND), U4.7 (GND), U5.3 (VSS), U5.5 (SDO), U5.8 (VSS), U5.9 (VSS), U7.12 (VSSA), U7.18 (VSS), U7.31 (VSS), U7.47 (VSS), U7.63 (VSS), U8.6 (GND), U8.8 (GND), U9.1 (GND), U12.2 (VN), U13.2 (VN), Y2.2 (GND), Y2.4 (GND)
IRQ_SLD: U1.8 (IRQ), U7.15 (PA1)
NRF24_CE_SLD: U1.3 (CE), U7.16 (PA2)
NRF24_CS_SLD: TP2.1 (1_1), U1.4 (~CSN), U7.14 (PA0)
NRST: D7.1, J4.08, R30.2, U7.7 (NRST)
unnamed: D1.1 (K), R5.1
unnamed: D2.1 (K), R8.2
unnamed: D3.1 (K), R6.2
unnamed: D4.1 (K), R9.2
unnamed: J2.8 (DAT1), R38.1
unnamed: J2.1 (DAT2), R21.2
unnamed: J4.07, R39.2
unnamed: R22.1, U7.21 (PA5)
unnamed: R23.1, U7.22 (PA6)
unnamed: R24.1, U7.23 (PA7)
unnamed: R27.1, U7.46 (PA13)
unnamed: R28.1, U7.49 (PA14)
unnamed: R29.1, U7.55 (PB3)
unnamed: R26.1, U7.58 (PB6)
unnamed: R25.1, U7.59 (PB7)
unnamed: R4.1, U7.34 (PB13)
unnamed: R35.1, U7.35 (PB14)
unnamed: R36.1, U7.36 (PB15)
unnamed: R31.2, U7.51 (PC10)
unnamed: R32.2, U7.52 (PC11)
unnamed: C32.1, U7.30 (VCAP_1)
unnamed: C38.1, U8.5 (C1)
SD_CS: D10.1, J2.2 (DAT3/CD), R3.2, TP8.1 (1_1), U7.26 (PB0)
SWCLK: D7.4, J4.04, R28.2
SWDIO: D7.5, J4.02, R27.2
SWO: D7.2, J4.06, R29.2
UART4_RX: D5.2, J4.10, R32.1
UART4_TX: D5.1, J4.09, R31.1

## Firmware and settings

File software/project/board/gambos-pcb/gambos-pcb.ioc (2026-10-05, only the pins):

Mcu.UserName=STM32F446RETx
PA0-WKUP.GPIO_Label=NRF24_CS
PA0-WKUP.Signal=GPIO_Output
PA1.GPIO_Label=IRQ
PA1.Signal=GPXTI1
PA10.GPIO_Label=LED2
PA10.Signal=GPIO_Output
PA11.GPIO_Label=LED1
PA11.Signal=GPIO_Output
PA13.Signal=SYS_JTMS-SWDIO
PA14.Signal=SYS_JTCK-SWCLK
PA15.GPIO_Label=S1
PA15.Signal=S_TIM2_CH1_ETR
PA2.GPIO_Label=NRF24_CE
PA2.Signal=GPIO_Output
PA3.GPIO_Label=FLASH_CS
PA3.Signal=GPIO_Output
PA5.Signal=SPI1_SCK
PA6.Signal=SPI1_MISO
PA7.Signal=SPI1_MOSI
PA9.GPIO_Label=LED3
PA9.Signal=GPIO_Output
PB0.GPIO_Label=SD_CS
PB0.Signal=GPIO_Output
PB13.Signal=SPI2_SCK
PB14.Signal=SPI2_MISO
PB15.Signal=SPI2_MOSI
PB3.Signal=SYS_JTDO-SWO
PB6.Signal=I2C1_SCL
PB7.Signal=I2C1_SDA
PC0.GPIO_Label=USR_BTN
PC0.Signal=GPXTI0
PC10.Signal=UART4_TX
PC11.Signal=UART4_RX
PC6.GPIO_Label=ESC_PWM
PC6.Signal=S_TIM3_CH1
PC7.GPIO_Label=S5
PC7.Signal=S_TIM3_CH2
PC8.GPIO_Label=S4
PC8.Signal=S_TIM3_CH3
PC9.GPIO_Label=S3
PC9.Signal=S_TIM3_CH4
PH0-OSC_IN.Signal=RCC_OSC_IN
PH1-OSC_OUT.Signal=RCC_OSC_OUT

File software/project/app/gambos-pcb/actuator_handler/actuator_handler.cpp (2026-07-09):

#include "actuator_handler.hpp"

#include "log.hpp"
#include "tim.h"

namespace {

float ServoAngleToPulseMs(uint32_t angle_deg) {
    if (angle_deg > 180U) {
        angle_deg = 180U;
    }

    return 1.0f + (static_cast<float>(angle_deg) * 2.0f / 180.0f);
}

} // namespace

ActuatorHandler::ActuatorHandler()
    : _motor(&htim3, TIM_CHANNEL_1), _servo1(&htim2, TIM_CHANNEL_1),
      _servo3(&htim3, TIM_CHANNEL_4), _servo4(&htim3, TIM_CHANNEL_3),
      _servo5(&htim3, TIM_CHANNEL_2) {}

bool ActuatorHandler::Initialize(void) {
    const float servo_center_pulse_ms = ServoAngleToPulseMs(90U);

    return _motor.SetDutyCycle(0U) &&
           _servo1.SetPulse(servo_center_pulse_ms) &&
           _servo3.SetPulse(servo_center_pulse_ms) &&
           _servo4.SetPulse(servo_center_pulse_ms) &&
           _servo5.SetPulse(servo_center_pulse_ms);
}

void ActuatorHandler::Start(void) {
    const bool motor_ok = _motor.Start();
    const bool servo1_ok = _servo1.Start();
    const bool servo3_ok = _servo3.Start();
    const bool servo4_ok = _servo4.Start();
    const bool servo5_ok = _servo5.Start();

    if (!motor_ok || !servo1_ok || !servo3_ok || !servo4_ok ||
        !servo5_ok) {
        LOG("ERROR: actuator_handler PWM start failed "
            "(motor=%u s1=%u s3=%u s4=%u s5=%u)\r\n",
            motor_ok,
            servo1_ok,
            servo3_ok,
            servo4_ok,
            servo5_ok);
    }
}

bool ActuatorHandler::SetServo1Angle(uint32_t angle_deg) {
    return _servo1.SetPulse(ServoAngleToPulseMs(angle_deg));
}

bool ActuatorHandler::SetServo3Angle(uint32_t angle_deg) {
    return _servo3.SetPulse(ServoAngleToPulseMs(angle_deg));
}

bool ActuatorHandler::SetServo4Angle(uint32_t angle_deg) {
    return _servo4.SetPulse(ServoAngleToPulseMs(angle_deg));
}

bool ActuatorHandler::SetServo5Angle(uint32_t angle_deg) {
    return _servo5.SetPulse(ServoAngleToPulseMs(angle_deg));
}

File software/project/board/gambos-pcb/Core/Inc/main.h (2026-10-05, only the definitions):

#define USR_BTN_Pin GPIO_PIN_0
#define USR_BTN_GPIO_Port GPIOC
#define USR_BTN_EXTI_IRQn EXTI0_IRQn
#define NRF24_CS_Pin GPIO_PIN_0
#define NRF24_CS_GPIO_Port GPIOA
#define IRQ_Pin GPIO_PIN_1
#define IRQ_GPIO_Port GPIOA
#define NRF24_CE_Pin GPIO_PIN_2
#define NRF24_CE_GPIO_Port GPIOA
#define FLASH_CS_Pin GPIO_PIN_3
#define FLASH_CS_GPIO_Port GPIOA
#define SD_CS_Pin GPIO_PIN_0
#define SD_CS_GPIO_Port GPIOB
#define ESC_PWM_Pin GPIO_PIN_6
#define ESC_PWM_GPIO_Port GPIOC
#define S5_Pin GPIO_PIN_7
#define S5_GPIO_Port GPIOC
#define S4_Pin GPIO_PIN_8
#define S4_GPIO_Port GPIOC
#define S3_Pin GPIO_PIN_9
#define S3_GPIO_Port GPIOC
#define LED3_Pin GPIO_PIN_9
#define LED3_GPIO_Port GPIOA
#define LED2_Pin GPIO_PIN_10
#define LED2_GPIO_Port GPIOA
#define LED1_Pin GPIO_PIN_11
#define LED1_GPIO_Port GPIOA
#define S1_Pin GPIO_PIN_15
#define S1_GPIO_Port GPIOA

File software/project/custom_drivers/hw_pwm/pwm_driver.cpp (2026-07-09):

#include "pwm_driver.hpp"
#include "stm32f4xx_hal_tim.h"

namespace {

constexpr uint32_t kTimCounterClockHz = 90'000'000U;

} // namespace

PwmDriver::PwmDriver(TIM_HandleTypeDef *htim, uint32_t channel)
    : _htim(htim), _channel(channel), _duty_cycle(0U) {}

bool PwmDriver::Start(void) {
    if (_htim == nullptr) {
        return false;
    }

    return HAL_TIM_PWM_Start(_htim, _channel) == HAL_OK;
}

bool PwmDriver::Stop(void) {
    if (_htim == nullptr) {
        return false;
    }

    // Makes CCxE = 0 or stops the whole timer if all channels are
    // disabled
    return HAL_TIM_PWM_Stop(_htim, _channel) == HAL_OK;
}

bool PwmDriver::SetDutyCycle(uint32_t duty_cycle) {
    if (_htim == nullptr) {
        return false;
    }

    if (duty_cycle > 100U) {
        duty_cycle = 100U;
    }

    const uint32_t arr = __HAL_TIM_GET_AUTORELOAD(_htim);
    const uint32_t ccr = (duty_cycle * (arr + 1U)) / 100U;
    __HAL_TIM_SET_COMPARE(_htim, _channel, ccr);
    _duty_cycle = duty_cycle;
    return true;
}

bool PwmDriver::SetPulse(float pulse_ms) {
    if (_htim == nullptr || pulse_ms <= 0.0f) {
        return false;
    }

    const uint32_t psc = _htim->Instance->PSC;
    const uint32_t arr = __HAL_TIM_GET_AUTORELOAD(_htim);
    const float tick_hz = static_cast<float>(kTimCounterClockHz) /
                          static_cast<float>(psc + 1U);
    const float pulse_ticks_f = (pulse_ms / 1000.0f) * tick_hz;

    if (pulse_ticks_f < 1.0f ||
        pulse_ticks_f > static_cast<float>(arr + 1U)) {
        return false;
    }

    const uint32_t ccr = static_cast<uint32_t>(pulse_ticks_f + 0.5f);
    __HAL_TIM_SET_COMPARE(_htim, _channel, ccr);
    _duty_cycle = (ccr * 100U) / (arr + 1U);
    return true;
}

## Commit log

2026-05-11 Docker environment fixes
    [gambos-pcb.csv, gambos-pcb.kicad_pcb, sensors_and_flash.kicad_sch]
2026-05-12 LEDs work
2026-05-12 LEDs work again
    [interface-jlink-swd.cfg]
2026-05-12 Fixed button, disabled its pull-up
2026-05-18 Added partial documentation about the project
    [MCU.kicad_sch, microcontroller.kicad_sch]
2026-05-19 Adjusted flashing firmware to the custom board to use only JLinkExe, no opencd fallback, simpler code and documentation
    [interface-jlink-swd.cfg]
2026-05-20 Ignore KiCad lock files (~*.lck)
2026-05-20 Added photo of the pcb during bring-up
2026-05-25 Added pdf file of the KiCad schematic
2026-06-02 Tested flash, pwm, i2c
2026-06-16 LittleFS integration and flash driver
2026-06-22 Changes for i2c and spi synchronization
2026-06-30 Initial commit for pwm handler
2026-07-07 Added pwm for servo control handler and driver
2026-07-09 Deleted the devkit folder, renamed from custom target pcb to gambos-pcb and renamed everything accordingly
2026-07-14 Sensors up and running
2026-07-24 Added drivers for sensors and sensing handler
2026-07-24 tested sensors, barometer does not work needs resoldering
    [bmp384.cpp, button_handler.cpp]
2026-07-25 Fixed a couple of stuff when syncing and formatting newly generated files from cubeMX
    [gambos-pcb.ioc]
2026-08-26 Split SD into block driver and FatFs export layer
    Move disk_* into sd_fs, drop boot SdHandler, and prepare
    flash reset + LOGS/NNNN.BIN exports.
    [board.cpp, sd_card.cpp]
2026-08-27 Regenerated code to include interrupts needed for the button and added interrupts needed for i2c
2026-08-28 The storage flow works and added a patch to expand the heap to 32 KB

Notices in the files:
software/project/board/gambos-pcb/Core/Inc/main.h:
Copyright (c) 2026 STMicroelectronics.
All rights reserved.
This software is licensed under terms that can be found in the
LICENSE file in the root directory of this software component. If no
